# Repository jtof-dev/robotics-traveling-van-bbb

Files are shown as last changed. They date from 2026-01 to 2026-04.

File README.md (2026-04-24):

# ball and beam robot

everything needed to power a ball and beam balance robot (bbb) using a stepper motor, including the code, parts lists, CAD model, and instructions. when you're done, check out our [inverted pendulum robot](https://github.com/jtof-dev/robotics-traveling-van-ipr) and our [website](https://sce.nau.edu/capstone/projects/EE/2026/RoboVan/)

```ascii flowchart
                              ┌─────────┐
                              │         │
                              │ initial │
                              │  boot   │
                              │         │
                              └────┬────┘
                                   │
            ┌───────────────┐      │      ┌─────────────┐
            │               │      │      │             │
            │ reset beam to │◄─────┼─────►│ set up pins │
            │    center     │      │      │ and sensor  │
            │               │      │      │             │
            └───────────────┘      │      └─────────────┘
                                   ▼
                              ┌────────┐
                              │        │
                              │ main() │
                              │        │
                              └────┬───┘
                                   │
                                   │
                                   │
                                   ▼
  ┌────────────────┐      ┌──────────────────┐      ┌───────────────┐
  │                │      │                  │      │               │
  │  send desired  ├─────►│ write a frame to ├─────►│ read time of  │
  │ angle to motor │      │ the touchscreen  │      │ flight sensor │
  │                │      │                  │      │               │
  └────────────────┘      └──────────────────┘      └────────────┬──┘
     ▲                                                           │
     │                                                           │
     │                                                           │
     │                                                           │
     │                                                           │
     │    ┌─────────────────────┐      ┌─────────────────────┐   │
     │    │                     │      │                     │   │
     └────┤ adjust output value │◄─────┤ run PID calculation │◄──┘
          │                     │      │                     │
          └─────────────────────┘      └─────────────────────┘
```

# notes

## directory structure

- **datasheets/**: datasheets for the specific parts used in this robot
- **lib/**: contains all submodules
- **scripts/**: all scripts commonly used while writing code
- **sims/**: any python scripts used to model the behavior of the inverted pendulum
- **src/**: our own written code, split into a `configuration.hpp` and `main.cpp`, along with some extra functions split off into individual files

# software

because there are no good screen libraries written for the pi pico, we are instead using one written for arduino, and then compiling a mixture of arduino and pico code

## building

- first, fetch all submodules with `git submodule update --init --recursive` or delete and re-clone all submodules with `scripts/submoduleSetup.sh`

- second, install two `arduino-cli` (and `arduino-cli` if needed) dependencies that get used in `CMakeLists.txt`:

```bash
arduino-cli core update-index --additional-urls https://github.com/earlephilhower/arduino-pico/releases/download/global/package_rp2040_index.json
arduino-cli core install rp2040:rp2040 --additional-urls https://github.com/earlephilhower/arduino-pico/releases/download/global/package_rp2040_index.json
```

then build with CMAKE (or with `scripts/buildFresh.sh`):

```bash
    mdkir build
    cd build
    cmake ..
    make
```

(note: updating configurations in `src/configuration.hpp` does not trigger a proper re-build, so only running `make` will often not be enough. instead re-run all of the commands or use `scripts/buildFresh.sh`)

## uploading

- to flash the compiled `.uf2`, either reboot the pico into BOOTSEL mode (hold the BOOTSEL button and plug in the pico), or use `picotool` (or `scripts/upload.sh`):

```bash
picotool load -f -x flash.uf2
```

## submodules

- [bodmer/TFT_eSPI](https://github.com/Bodmer/TFT_espi)
- [raspberrypi/pico-sdk](https://github.com/raspberrypi/pico-sdk)
- [yspreen/VL53L0X-driver-pico-sdk-cpp](https://github.com/yspreen/VL53L0X-driver-pico-sdk-cpp)

## sims

- located in `sims/`, and models the expected behavior of the robot. theoretically, it should produce similar gain values to what will be used on the physical robot
- the python environment is managed with `uv`:

```bash
uv sync
uv run main.py
```

or, install `matplotlib` and run normally

# hardware

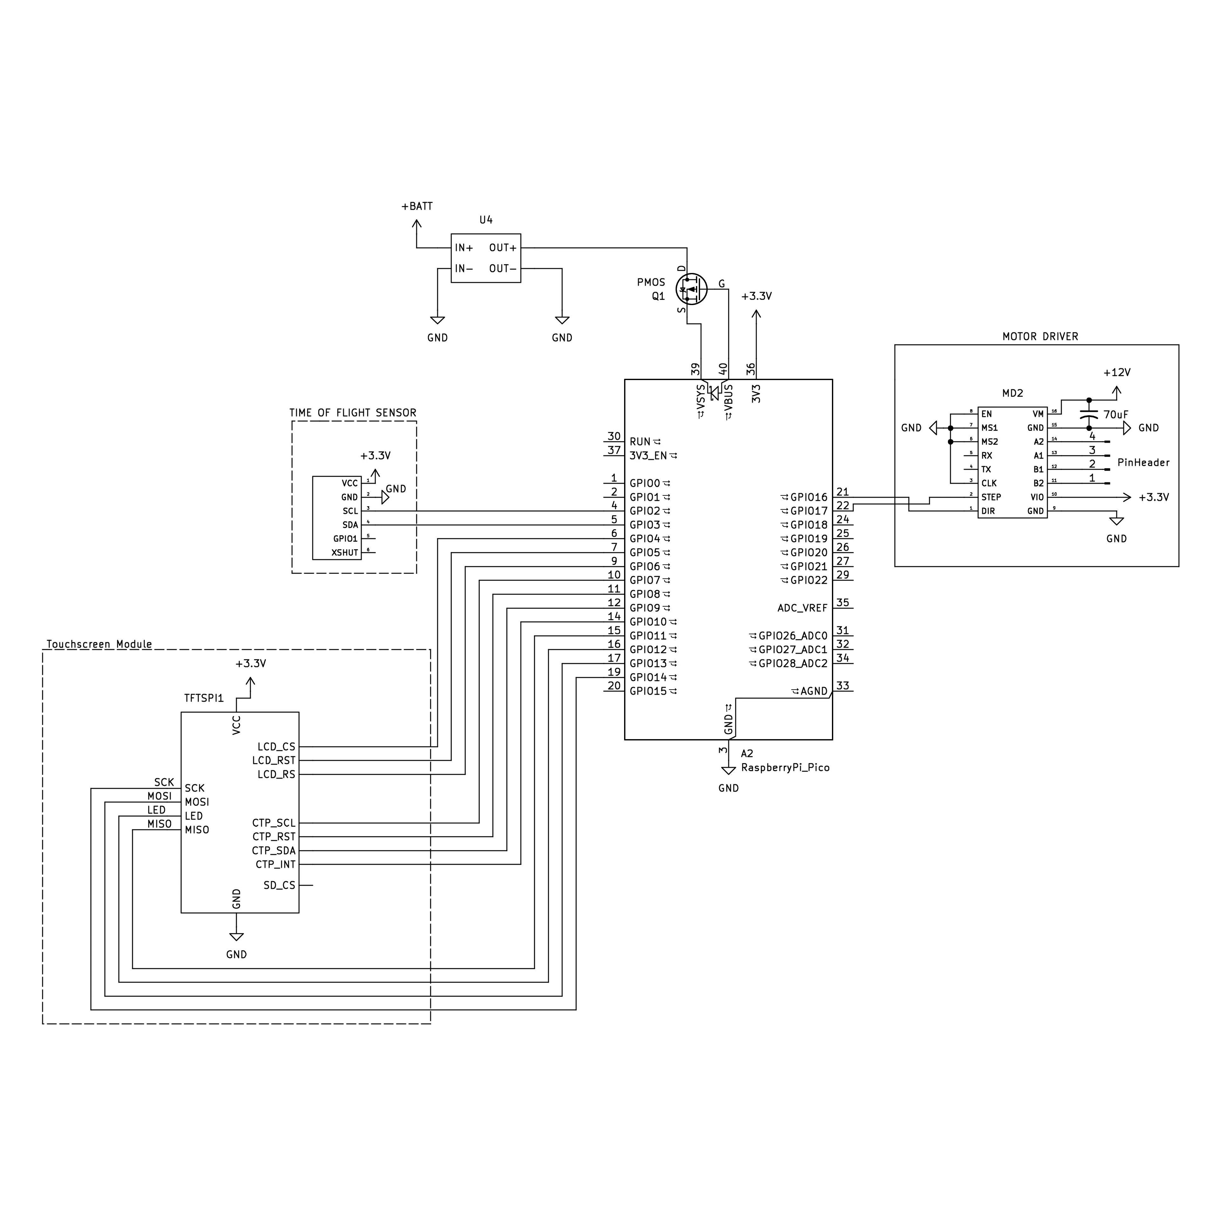
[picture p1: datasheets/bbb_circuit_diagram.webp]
circuit diagram


- for CAD model assembly and instructions, check out [`CAD/`](https://github.com/jtof-dev/robotics-traveling-van-bbb/tree/main/CAD)

## parts list

- [NEMA 17](https://a.co/d/05dRpuKu) stepper motor
- raspberry pi pico or [RP2040](./datasheets/RP2040_datasheet.pdf) compatible board
- [TMC2209](./datasheets/TMC2209_datasheet.pdf) stepper motor driver
- touchscreen with [ST7796S](./datasheets/ST7796S_datasheet.pdf) display driver
- [VL53L0X](./datasheets/VL53L0X_datasheet.pdf) time of flight sensor

### generic parts

- 4-pack of 3.3V batteries (in series for 13V total), matching BMS, and charger
  - be sure to match max voltage, current, and battery chemistry type between all three components
- step-down voltage converter to 3.3V
- 470uF 25V electrolytic capacitor

## pin configuration

### RP2040

| **pin** | **connection** |
| :--- | :--- |
| VIN | schottky diode cathode |
| GND | buck converter GND |
| 3V3 | to rail on protoboard  |
| pin 6 | I2C1 SDA on VL53l0X |
| pin 7 | I2C1 SCL on VL53l0X |
| pin 16  | STEP on TMC2209 |
| pin 17  | DIR on TMC2209 |

### ST7796S touchscreen

| display pin | pi pico pin | notes / function | wire color |
| :--- | :--- | :--- | :--- |
| VCC | external 3.3V | power for the display | red |
| GND | common GND | ground | black |
| LCD_CS | GP21 | TFT chip select (`TFT_CS`) | orange |
| LCD_RST | GP20 | TFT reset (`TFT_RST`) | yellow |
| LCD_RS | GP22 | TFT data/command (`TFT_DC`) | green |
| SDI (MOSI) | GP19 | SPI data input (`TFT_MOSI`) | blue |
| SCK | GP18 | SPI clock (`TFT_SCLK`) | purple |
| LED | 3.3V | backlight power. connect to 3.3V external power, it will overdraw the pico if connected to a data pin | white |
| SDO (MISO) | GP0 | SPI data output (`TFT_MISO`) | gray |
| CTP_SCL | GP3 | I2C1 clock (capacitive touch) | orange |
| CTP_RST | GP6 | touch reset | yellow |
| CTP_SDA | GP2 | I2C1 data (capacitive touch) | green |
| CTP_INT | GP7 | touch interrupt | blue |
| SD_CS | -- | SD card chip select (shares SPI bus with TFT) | -- |

### TMC2209 stepper motor driver

| **pin** | **connection source** | **function**  | **notes** |
| --- | --- | --- | --- |
| VM | 12V power | motor voltage | -- |
| GND | 12V GND | power ground  | -- |
| VIO | 3.3V (pico) | logic voltage | -- |
| GND | GND (pico) | logic ground  | -- |
| STEP | pin 16 (pico) | step signal | -- |
| DIR | pin 17 (pico) | direction | -- |
| EN | GND (pico) | enable | active low (always ON) |
| MS1 | -- | microstep 1 | active low (for 1/8 microstepping) |
| MS2 | -- | microstep 2 | active low (for 1/8 microstepping) |
| A1 | A+ | phase A | red |
| A2 | A- | phase A | black |
| B1 | B+ | phase B | yellow |
| B2 | B- | phase B | blue |

### VL53l0X time of flight sensor

| **pin** | **pico pin / rail** | **function** | **notes** |
| --- | --- | --- | --- |
| VCC | 3.3V rail | power | -- |
| GND | GND rail | ground | -- |
| SDA | GP6 (pin 9) | I2C1 SDA | primary data |
| SCL | GP7 (pin 10) | I2C1 SCL | primary clock |
| XSHUT | -- | shutdown | leave disconnected or pull high |
| GP101 | -- | interrupt | not required for basic ranging  |

# todo

- [ ] make a robust reset that doesn't involve turning on and off
- [ ] make the set point controllable through screen
- [x] detect ball nonsense (i.e its stuck on one side)
- [x] detect absense of ball 
- [x] implement the screen

# contributors

### [Kyle Draper](https://github.com/Kdra-bit)

- developed the electronics and balancing software for the ball and beam balance robot

### [Andy Babcock](https://github.com/jtof-dev)

- assisted with the balancing software and assembly

### [Kaden Zaremba](https://github.com/kadenisuhhh)

- developed the touchscreen software

### [David Jimenez]()

- assisted with the electronics design and assembly

### [Freddy Rivera](https://www.linkedin.com/in/freddy-rivera-791513268/)

- developed the CAD model and helped with assembly

### [Florence Fasugbe](https://www.linkedin.com/in/florence-fasugbe/)

- developed the CAD model and helped with assembly

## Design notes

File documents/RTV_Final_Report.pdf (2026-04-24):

# Robotics Traveling Van

# Final Design Report

### Freddy Rivera – Project Manager

### Colin Parsinia – Manufacturing Lead

### Florence Fasugbe – Design Lead

### Andres Gonzales – Programming Lead

### Fall 2025-Spring 2026

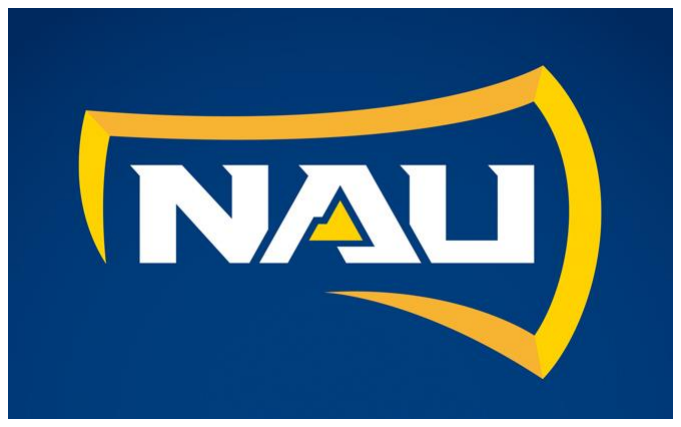
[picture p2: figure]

Project Sponsor: Dr. Michael Shafer

Faculty Advisor: Professor David Willy

Sponsor Mentor: Sethuprasad Gorantla

Instructor: Professor David Willy

i

## DISCLAIMER

This report was prepared by students as part of a university course requirement. While considerable effort has been put into the project, it is not the work of licensed engineers and has not undergone the extensive verification that is common in the profession. The information, data, conclusions, and content of this report should not be relied on or utilized without thorough, independent testing and verification. University faculty members may have been associated with this project as advisors, sponsors, or course instructors, but as such they are not responsible for the accuracy of results or conclusions.

ii

## EXECUTIVE SUMMARY

The Robotics Traveling Van project aims to design and develop two low-cost, transportable educational robots that demonstrate core control-system engineering concepts for K–12 outreach. Sponsored by our client, the goal is to create systems that are safe, durable, engaging, and capable of visually illustrating feedback control in classroom environments. The project spans two semesters, with the first focused on research, concept development, prototyping, and feasibility analysis.

Two robots were selected for development: Robot #1, an Inverted Pendulum Robot, and Robot #2, a Ball-on-Plate Robot. These concepts were chosen based on customer requirements, benchmarking, manufacturability, educational value, and system complexity. Throughout the Fall semester, the team completed detailed requirements definition, House of Quality, literature review, morphological chart, and decision matrices that guided the selection of the final designs.

For Robot #1, the team investigated pendulum dynamics, mass distribution, and actuator requirements to validate that the system could be controlled within safe operating limits. Structural concepts were evaluated for durability and stability, and a final frame design was selected based on manufacturability and robustness. Early prototyping confirmed feasibility and informed next semester’s full build and controller development.

For Robot #2, multiple concepts were researched before selecting the Ball-on-Plate mechanism due to its strong educational impact and clear visualization of closed-loop control. A Failure Modes and Effects Analysis identified critical risks such as motor overheating, unstable motion, and sensing error. A Ball-on-Beam prototype was constructed to validate sensing, actuation, and motor torque requirements prior to scaling to the full plate system. Engineering calculations confirmed that the chosen stepper motors provide sufficient torque with a comfortable safety factor. A detailed Bill of Materials was developed for the final Ball-on-Beam system, along with planned testing procedures for response time, stability, and safety.

Budget tracking, scheduling, and resource planning were completed for both robots, keeping the project within financial constraints. The team then began the process of ordering materials and electrical components so fabrication and system assembly could begin. 3D printers were acquired and a majority of the major components of the system were fabricated using said systems, with minor machining for the few non plastic parts. With both systems physical components assembled testing began for each robot focusing on safety and dimensions, battery endurance, interface and control systems, PID stability, and sensor calibration for both robots. Additionally, robot 1 was subjected to a drop test to ensure its structural integrity in the event of it rolling off a table, and a final bill of materials audit was performed to evaluate the exact cost of an individual unit.

At the current time Robot #2 is fully functional and ready to be handed off to the client for use, while Robot #1 is only capable of movement and not fully capable of balancing its pendulum, though the client has been briefed on the state of Robot #1 and has approved the descoping of required functionality. Looking forward for both robots, the first major step is to get the designed circuit boards printed and implemented into the robots control systems, further wire and electrical system organization, and with a fully functional electrical system implemented into Robot #1 its code can be properly tested & tuned to balance the pendulum.

iii

## TABLE OF CONTENTS

## Contents

DISCLAIMER | 1
EXECUTIVE SUMMARY | 2
TABLE OF CONTENTS | 3
1 | BACKGROUND | 1
1.1 | Project Description | 1
1.2 | Deliverables | 1
1.3 | Success Metrics | 1
2 | REQUIREMENTS | 3
2.1 | Customer Requirements (CRs) | 3
2.2 | Engineering Requirements (ERs) | 3
2.3 | House of Quality (HoQ) | 5
3 | Research and Benchmarking for the Inverted Pendulum Robot | 5
3.1 | Benchmarking for Inverted Pendulum (Robot 1) | 5
3.2 | System-Level Benchmarking | 6
3.2.1 | Balancing Sensor | 6
3.2.2 | Microcontroller | 7
3.2.3 | Motors | 7
3.3 | Literature Review (Robot 1) | 8
3.3.1 | Andres | 8
3.3.2 | Colin | 10
3.4 | Mathematical Modeling (Robot 1) | 12
3.4.1 | Control System and Pendulum Dynamics – Andres Gonzales | 12
3.4.2 | Pendulum Robot Frame Structural Integrity – Colin Parsinia | 12
3.4.3 | Cart/Angular Acceleration for an Inverted Pendulum – Freddy Rivera | 13
3.4.4 Inverted Pendulum Robot , Reference within Humans – Florence L. Fasugbe | 14
4 | Research and Benchmarking for the Ball-On-Beam Robot | 15
4.1 | Benchmarking for Ball-On-Beam (Robot 2) | 15
4.2 | System-Level Benchmarking | 15
4.2.1 | Distance Sensor Benchmarking | 16
4.2.2 | Microcontroller Benchmarking | 16
4.2.3 | Actuator Benchmarking | 16
4.3 | Literature Review (Robot 2) | 17
4.3.1 | Freddy | 17
4.3.2 | Florence | 20
4.4 | Mathematical Modeling (Robot 2) | 21
4.4.1 | Dynamic Physical Limits – Freddy Rivera | 21
4.4.2 | Control System Architecture – Freddy Rivera | 22
4.4.3 | Dynamics of the Beams Structure with - Florence L. Fasugbe | 22
5 | Design Concepts for the Inverted Pendulum Robot | 24
5.1 | Functional Decomposition | 24
5.2 | Concept Generation | 24
5.3 | Selection Criteria | 26
5.4 | Concept Selection | 27
6 | Design Concepts for the Ball on Beam System | 28
6.1 | Functional Decomposition | 28
6.2 | Concept Generation | 29
6.3 | Selection Criteria | 31

iv

6.4 | Concept Selection | 32
7 | Schedule and Budget | 35
7.1 | Schedule | 35
7.2 | Budget | 35
7.3 | Bill of Materials (BoM) | 36
8 | Design Standards | 39
8.1 | Design Standards Research | 39
Robot 1: | 39
8.1.1 | Robot 1 Annotated Bibliography: | 40
8.1.2 | Robot 2: | 40
8.1.3 | Annotated Bibliography: | 42
8.2 | Design Standards Used | 43
8.2.1 | Robot 1 & 2: | 43
9 | Design Validation and Initial Prototyping for Both Systems | 45
9.1 | Failure Modes and Effects Analysis (FMEA) for Inverted Pendulum | 45
9.2 | Failure Modes and Effects Analysis (FMEA) for Ball-on-Beam | 46
9.3 | Initial Prototyping | 48
9.3.1 | Robot 1 Prototype | 48
9.3.2 | Robot 2 Prototype | 50
9.4 | Other Engineering Calculations | 51
9.4.1 | Other Engineering Calculations – Colin Parsinia & Andres Gonzales | 51
9.4.1.1 | Electrical Load Analysis | 51
9.4.2 | Other Engineering Calculations for Robot 2– Freddy Rivera & Florence Fasugbe52
9.4.2.1 | System Parameters | 53
9.4.2.2 | Plant Model Summary | 53
9.4.2.3 | Available Motor Torque at Operating Conditions | 54
9.4.2.4 | Load Case 1: Static Torque Requirement | 54
9.4.2.5 | Load Case 2: Maximum Allowable Angular Acceleration | 54
9.4.2.6 | Total Rotational Inertia | 54
9.4.2.7 | Required Dynamic Torque | 54
9.4.2.8 | Load Case 3: Maximum Recoverable Beam Angle (Rolling Without Slip)54
9.4.2.9 | Battery Runtime Estimate | 55
9.4.2.10 | Structural Factor of Safety Summary | 55
9.4.2.11 | Design Implications | 55
9.5 | Future Testing Potential | 55
10 | Final Hardware | 56
10.1 | Final Physical Design – Robot #1 | 56
10.2 | Final Physical Design – Robot #2 | 61
11 | Final Testing | 65
11.1 | Top level testing summary table | 65
11.2 | Detailed Testing Plan | 66
11.2.1 | Test 1: Safety & Dimensions | 66
11.2.1.1 | Summary | 66
11.2.1.2 | Procedure | 66
11.2.1.3 | Results | 66
11.2.2 | Test 2: Bill of Materials Audit | 67
11.2.2.1 | Summary | 67
11.2.2.2 | Procedure | 67
11.2.2.3 | Results | 67
11.2.3 | Test 3: Chassis Drop Test | 67
11.2.3.1 | Summary | 67

v

11.2.3.2 | Procedure | 67
11.2.3.3 | Results | 67
11.2.4 | Test 4: Battery Endurance | 67
11.2.4.1 | Summary | 67
11.2.4.2 | Procedure | 68
11.2.4.3 | Results | 68
11.2.5 | Test 5: Interface & Control | 68
11.2.5.1 | Summary | 68
11.2.5.2 | Procedure | 68
11.2.5.3 | Results | 68
11.2.6 | Test 6: PID Stability & Settling | 69
11.2.6.1 | Summary | 69
11.2.6.2 | Procedure | 69
11.2.6.3 | Results | 69
11.2.7 | Test 7: Sensor Calibration | 69
11.2.7.1 | Summary | 69
11.2.7.2 | Procedure | 69
11.2.7.3 | Results | 70
12 | Future work | 71
13 | Conclusion | 72
14 | REFERENCES | 73
15 | APPENDICES | 77
15.1 | Appendix A: Bill of materials (BOM) of Robot #1 and #2 for the RTV Capstone throughout
the 2026 spring semester; listing the products used to manufacture the final product with the name of
parts, vendor, costs, quantity, link of purchases, and dimensions of the products | 77

1 | P a g e

## 1 BACKGROUND

This chapter provides an overview of the project background and objectives. It summarizes the project description, deliverables, and success metrics, outlining how the dual-robot design aligns with client expectations for highly durable, interactive engineering outreach tools designed to entice K-12 students to Northern Arizona University (NAU).

### 1.1 Project Description

The goal of this capstone project is to design and manufacture two highly interactive educational robots that serve as traveling outreach props for NAU. Sponsored by Dr. Michael Shafer, the project aims to create low-cost, durable learning platforms that visually demonstrate fundamental control system principles to inspire K-12 students to pursue STEM.

Each robot fulfills a unique educational role:

- Robot #1 (Inverted Pendulum): Demonstrates Newtonian dynamics, physical mobility, and spatial tracking through magnetic encoders (with active PID balancing formally descoped to prioritize structural resilience and reliable component integration).
- Robot #2 (Ball-on-Beam): A 1-axis, direct-drive system designed to visually demonstrate active Proportional-Integral-Derivative (PID) feedback control through hands-on interaction.

While the project was allocated a total budget of $5,000, the client's core directive was mass-producibility for fleet deployment. To meet this, the team successfully engineered both platforms utilizing off-the-shelf electronics and standard 3D-printed PLA, achieving a highly scalable reproduction cost of under $300 (approximately $240) per unit. Throughout the academic year, the project evolved from theoretical mathematical modeling to the final delivery of robust, physical hardware capable of surviving high-impact K-12 environments.

### 1.2 Deliverables

The major deliverables for this project include:

1. Two fully manufactured educational robots (the Inverted Pendulum and the Ball-on-Beam) equipped with integrated touchscreen interfaces to serve as transportable K-12 outreach tools.
2. An open-source digital repository hosting all necessary CAD models, microcontroller code bases, and mass-manufacturing blueprints, and bill of materials (BOMs) to ensure the client or future engineering teams can seamlessly replicate the fleet.
3. Comprehensive engineering documentation detailing the complete design cycle, functional decompositions, risk mitigation (FMEA) strategies, and finalized system parameters.

### 1.3 Success Metrics

Project success is evaluated against the rigorous customer and engineering requirements established during the early design phases. Key success criteria include:

- Platforms must effectively translate invisible math into observable physical motion: observable physical motion, whether through dynamic spatial tracking or active feedback control loops, to captivate K-

2 | P a g e

12 audiences.

- Interactive Interface: Students must be able to safely alter system variables via the onboard touchscreens without requiring external computer hardware.
- Classroom Durability: The physical chassis must withstand the wear and tear of a K-12 environment. By utilizing thickened 3D-printed PLA architectures and robust mechanical fasteners, both systems are engineered for high structural resilience during continuous transport and hands-on demonstrations.
- Untethered Reliability: Systems must operate completely independently of wall power. Custom 14.8V LiFePO4 battery arrays were integrated to successfully sustain continuous demonstrations for over 90 minutes.
- Mass Producibility & Budget: The final per-unit cost must remain strictly under the $300 target to allow NAU to economically reproduce the designs for future traveling van deployments.

Success has ultimately been verified through final physical testing, performance analysis, and client evaluation, confirming that the constructed platforms meet the rigid safety, durability, and cost metrics required to serve as permanent NAU engineering outreach tools.

3 | P a g e

## 2 REQUIREMENTS

The requirements section establishes the foundational parameters of the project, translating qualitative client needs into measurable, quantifiable engineering goals. Because this project is designed as an interactive engineering outreach spectacle rather than a static classroom tool, the requirements heavily emphasize durability, visual engagement, and mass producibility. Customer Requirements (CRs) describe what the client expects the final platforms to accomplish in plain, qualitative terms. Engineering Requirements (ERs) then translate those needs into verifiable parameters with measurable targets, units, and one-sided, two-sided, or binary constraints. Finally, the House of Quality (HoQ) matrix visually maps the relationships between CRs and ERs, highlighting critical design trade-offs and driving prioritization decisions.

### 2.1 Customer Requirements (CRs)

The primary client goal is to create a transportable, interactive spectacle that demonstrates feedback control principles to K-12 students, with the intent of enticing them to pursue STEM at NAU. The CRs below stem from the intended user base, the need for mass producibility, and the survivability demands of high-impact outreach environments.

Table 1: Customer Requirements

CR # | Title | Description
CR01 | Durable | The robot must withstand frequent use, rough handling, and physical impacts common in K-12 outreach environments.
CR02 | Inexpensive | The total production cost must be low enough to enable fleet-wide mass production for NAU outreach programs.
CR03 | Functional | The system must effectively demonstrate the principles of feedback control through observable, repeatable mechanical motion.
CR04 | Battery Powered | The system must operate completely untethered from external power sources to ensure maximum flexibility and safety during demonstrations.
CR05 | Interactive Interface | The interface must allow users to directly adjust control parameters and initiate demonstrations intuitively.
CR06 | Compact Operating Space | The robot must safely function on a standard classroom or lab table without requiring excessive operational clearance.
CR07 | Educational / Engaging | The design must help students visually and conceptually connect physical robot motion with control theory concepts.
CR08 | Kid-Friendly Design | The product must be visually appealing, approachable, and physically safe for students of all ages.

### 2.2 Engineering Requirements (ERs)

The ERs below translate each qualitative CR into a strict, verifiable target. All constraints are expressed with explicit units and limit types. Note regarding ER07: Following mid-project client review, active PID balancing for the Inverted Pendulum (Robot 1) was formally descoped in favor of focusing on dynamic mobility. ER07 therefore applies exclusively to the Ball-on-Beam (Robot 2) automated balancing system.

4 | P a g e

Table 2: Engineering Requirements

ER # | Title | Target | Unit | Constraint Type | Linked CR(s) | Rationale
ER01 | Overall Dimensions | < 12 × 12 × 12 | inches | One-sided (max) | CR06, CR08 | Ensures high transportability and compatibility with standard storage and tabletop outreach setups.
ER02 | Runtime / Power Source | > 30 | minutes | One-sided (min) | CR03, CR04 | Must sustain continuous operation through a full outreach event on a single charge.
ER03 | Control Hardware | Raspberry Pi (RP2040/Pico) | Binary (Yes/No) | Binary | CR03, CR05 | Microcontroller must support real-time sensor filtering and drive interactive touchscreen displays.
ER04 | Electrical Safety | Fully Enclosed Wiring | Binary (Yes/No) | Binary | CR08 | Complies with U.S. CPSC guidelines; eliminates exposed conductors and short-circuit risk around children.
ER05 | Drop Test Survivability | 36 | inches | One-sided (min) | CR01 | Must survive a fall from a standard laboratory table without mechanical failure.
ER06 | Manufacturing Cost | < 300 | USD/unit | One-sided (max) | CR02 | Keeps per-unit reproduction cost low enough for NAU to scale the project into a larger fleet.
ER07 | PID Settling Time | < 15.0 | seconds | One-sided (max) | CR03, CR07 | Allows users enough time to observe system oscillation before equilibrium is reached. (Robot 1 active balancing descoped; applies to Robot 2 only.)
ER08 | Sharp Edge Radii | ≥ 3 | mm | One-sided (min) | CR08 | All exposed edges must be chamfered or filleted to eliminate laceration hazards per CPSC guidelines.
ER09 | Pinch-Point Clearance | ≥ 16.5 | mm | One-sided (min) | CR08 | Maintains safe spacing between all moving parts to prevent finger entrapment per toy safety standards.
ER10 | Emergency Stop Response | < 1.0 | seconds | One-sided (max) | CR08 | A physical cutoff must instantly sever power to all actuators in the event of

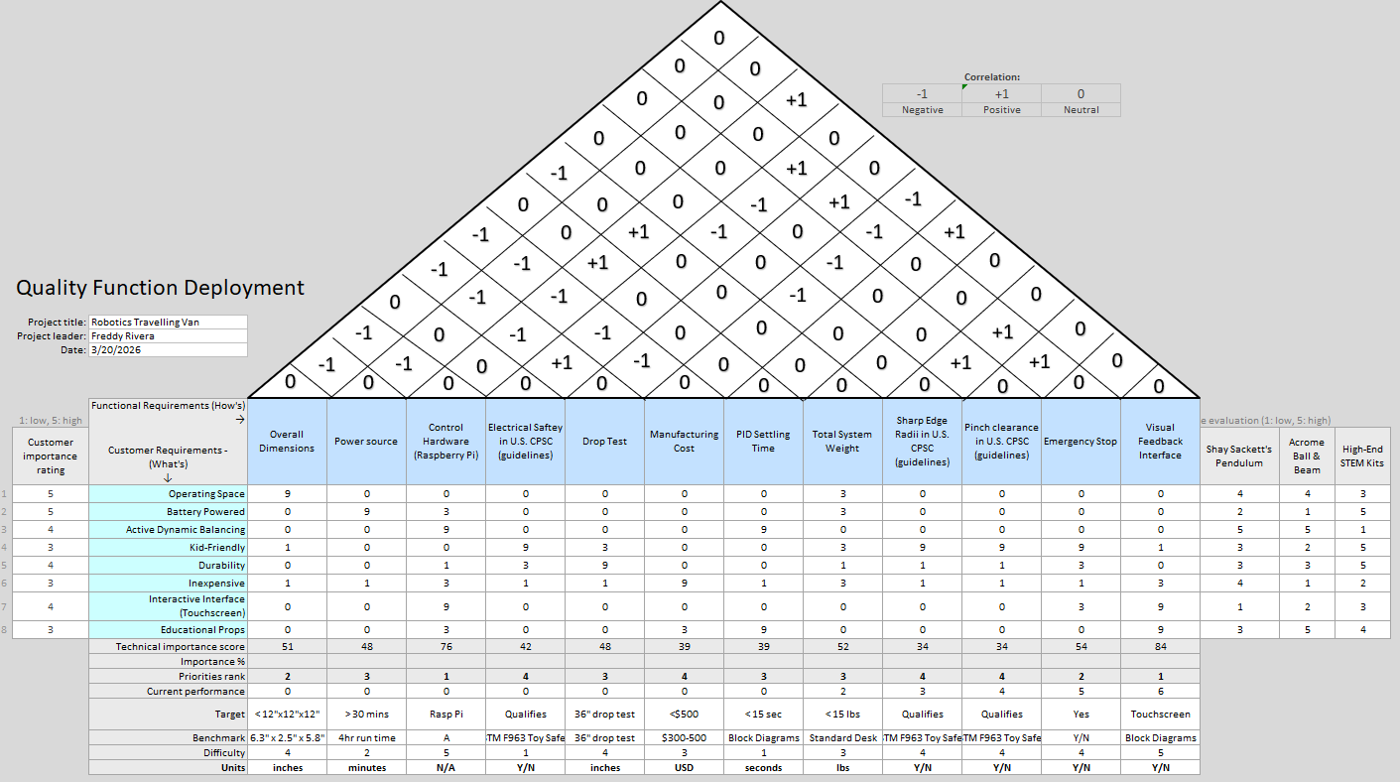
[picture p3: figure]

5 | P a g e
| | | | | | unpredictable behavior.
ER11 | Visual Feedback Interface | LCD Touchscreen | Binary (Yes/No) | Binary | CR05, CR07 | Provides the primary interaction point for students to modify control variables and observe live mechanical data.

### 2.3 House of Quality (HoQ)

Figure 1: House of Quality

## 3 Research and Benchmarking for the Inverted Pendulum Robot

### 3.1 Benchmarking for Inverted Pendulum (Robot 1)

The development of our inverted pendulum robot is guided by benchmarking against established, state-of-the-art systems. Because self-balancing robotics is a well-documented field, there is a wealth of existing control architectures and mechanical designs to inform our original build.

The systems selected for system-level comparison include Shay Sackett’s Pendulum Robot, a Voice-Controlled Self-Balancing Robot, and an Instructables Line-Following Robot. The first two benchmarks serve as direct

6 | P a g e

mechanical and control comparisons for two-wheeled inverted pendulums. The third system serves as a conceptual benchmark for K-12 user interactivity.

### 3.2 System-Level Benchmarking

Table 3: Robot 1 Benchmarking – top level systems
System | Reference
Example | Key Features | Relation to Our
Concept | Notes / Takeaways

Sackett’s
Pendulum
Robot

Shay Sackets
Self Balancing
Pendulum
Robot [34]

2-Wheeled
Pendulum robot
capable out
automatic balancing
mid operation

Provides solid baseline
design for a 2-Wheeled
Pendulum robot

Establishes basic ideas,
equations, principles, and systems that go into
pendulum robots

Self-Balancing
Interactive
Robot

Voice controlled
self-balancing
pendulum robot
[19]

2-Wheeled
Pendulum robot
capable of receiving
voice commands and
interacting with
external systems

Proof of concept of a
voice-controlled
pendulum robot for
good interactivity

Presents alternative,
higher-level control
mechanisms. While highly
complex, it validates the
feasibility of advanced
interactivity.

Instructible
Line
Following
Robot

Instructable
Line following
robot [33]

Simple 3 wheeled
line following robot,
easy system to
assemble and
explain

The tactile interactivity
(users physically
drawing the path the
robot follows) is ideal
for K-12 engagement.

When designing our robot,
achieving a similar level
of intuitive, hands-on
interactivity is a primary design target.

### 3.2.1 Balancing Sensor

To ensure optimal performance, durability, and cost-effectiveness, the primary sub-systems of our inverted pendulum robot, specifically the balancing sensor, microcontroller, and actuators were benchmarked against industry-standard alternatives.

Table 4: Robot 1 Benchmarking – sensors

Feature /
Metric

Alternative 1: IMU (e.g.,
MPU6050) [25]

Alternative 2: Optical
Encoder [50]

Selected: Magnetic
Encoder

Measurement
Method | Gravity/Acceleration Vectors | Light interruption via slotted disk

Magnetic field variation
(Hall Effect)

7 | P a g e

Susceptibility to
Drift

High (Requires
Kalman/Complementary filters) | None | None

Environmental
Durability | High | Low (Sensitive to dust/debris)

High (Contactless and
sealed)

Integration
Complexity | High (Complex math overhead) | Medium | Low (Direct digital/analog output)

While Inertial Measurement Units (IMUs) are the standard, our cart-and-pendulum mechanical design allows for a fixed axis of rotation. Benchmarking reveals that placing a magnetic encoder directly on this axis provides immediate, absolute angular position data. This eliminates the computational overhead and signal drift associated with filtering IMU data, while offering greater physical durability than an optical encoder.

### 3.2.2 Microcontroller

The microcontroller must be capable of rapidly polling the encoder, computing the PID algorithm, and outputting precise PWM signals to the motor drivers without stalling.

Table 5: Robot 1 Benchmarking - microcontroller

Feature / Metric Alternative 1: Arduino Uno (ATmega328P) [41]

Alternative 2:
ESP32 [35]

Selected: Raspberry Pi Pico (RP2040)
Clock Speed | 16 MHz | 240 MHz | 133 MHz
Architecture | 8-bit, Single-Core | 32-bit, Dual-Core | 32-bit, Dual-Core (ARM Cortex-M0+)

Programmable
I/O (PIO) | No | No | Yes (Dedicated PIO state machines)
Cost | ~$20.00 | ~$10.00 | ~$4.00

The Arduino Uno is heavily documented but severely limited by its 16 MHz clock speed, which can introduce latency into high-frequency control loops. While the ESP32 offers superior processing power and wireless capabilities, it introduces unnecessary power consumption and complexity for this specific scope. The Raspberry Pi Pico is the optimal benchmarked choice; its dual-core architecture allows one core to continuously poll the high-resolution magnetic encoder while the second core calculates the PID response and drives the motors, all at a highly cost-effective price point.

### 3.2.3 Motors

The actuation system must move the base cart rapidly in two directions to keep the pendulum balanced. Our mechanical design utilizes a 4-wheel cart base requiring integrated motors.

8 | P a g e

Table 6. Robot 1 Benchmarking - actuators

Feature /
Metric

Alternative 1: NEMA 17
Stepper Motors [8]

Alternative 2:
Brushless DC (BLDC)
[17]

Selected: 520 DC Reduction Motors (L-Type)

Control
Method

Step pulses (Open-loop
precise)

Electronic Speed
Controller (ESC)

PWM via H-Bridge (L298N /
TB6612FNG)

Torque at
Low Speeds | Very High | Low to Medium | High (Due to integrated
| | | gearbox)

Form Factor /
Mounting | Bulky, heavy | Compact | L-Type configuration (Ideal for
| | | chassis)
Cost & Complexity | High (Requires heavy
| drivers) | Very High | Low (Simple integration)

Stepper motors offer excellent positional accuracy but suffer from a low top-speed and significant weight, BLDC motors provide rapid response times but require expensive ESCs and complex commutation logic. The 520 L-Type DC gear motors were selected because their integrated reduction gearboxes provide the necessary torque to move the 4-wheel cart abruptly. Furthermore, the L-shape form factor is geometrically advantageous for maximizing internal chassis space, and they are easily driven by standard, low-cost H-bridge motor controllers.

### 3.3 Literature Review (Robot 1)

### 3.3.1 Andres

[1] S. O. Fadlallah and K. M. Goher, “Bacterial foraging-optimized PID control of a two-wheeled machine with a two-directional handling mechanism,” Robotics and Biomimetics, vol. 4, no. 1, p. 5, 2017.

This paper presents an innovative PID control method optimized through bacterial foraging algorithms for a two-wheeled robot. Its approach to handling two-directional motion is relevant for our pendulum robot’s control system, offering insights on advanced PID tuning. We will reference this to support our control strategy development, particularly for improving robot stability and response.

[2] X. Yu, Y. Fan, S. Xu, and L. Ou, “A self-adaptive SAC-PID control approach based on reinforcement learning for mobile robots,” International Journal of Robust and Nonlinear Control, vol. 31, no. 21, pp. 8389–8408, 2021.

This article discusses a reinforcement learning-based adaptive PID control for mobile robots, enhancing adaptability in dynamic environments. It applies to our project by informing adaptive control techniques to improve robot performance under varying load and terrain. We will cite this when describing our adaptive control algorithms.

9 | P a g e
[3] S. Jin and Y. Ou, “A wheeled inverted pendulum learning stable and accurate control from demonstrations,” Applied Sciences, vol. 9, no. 24, p. 5279, 2019.

The study explores learning-based control methods for wheeled inverted pendulums, focusing on stability and accuracy through demonstration learning. This is directly relevant for our pendulum robot’s balancing and control challenges. We will reference it to justify the use of machine learning or demonstration data in refining control models.

[4] S. Roy, S. B. Roy, and I. N. Kar, “Adaptive-robust control of Euler-Lagrange systems with linearly parametrizable uncertainty bound,” IEEE Transactions on Control Systems Technology, vol. 26, no. 5, pp. 1842– 1850, 2018. (Note: The title was slightly adjusted upon final publication from the preprint). This paper provides theoretical foundations and practical applications for adaptive-robust control in Euler-Lagrange systems, addressing uncertainties common in mechanical systems like our robot. We will reference this to underpin the robustness of our control system design in the face of modeling inaccuracies.
[5] K. Ogata, System Dynamics, 4th ed. Upper Saddle River, NJ: Prentice Hall, 2003, ch. 11.

Ogata’s textbook is a fundamental resource on system dynamics, providing key concepts in modeling and controlling dynamic mechanical systems, including pendulums. We will cite this as a primary reference for the theoretical background of pendulum dynamics and control principles applied in our design.

[6] PythonRobotics, “Inverted Pendulum Control,” GitHub repository. [Online]. Available: https://github.com/AtsushiSakai/PythonRobotics

This open-source repository provides practical algorithms for inverted pendulum control, including simulation and implementation examples. We will use it as a resource for algorithm development and benchmarking, referencing it when describing our control software framework.

[7] zjor, “Inverted Pendulum on a Cart,” Arduino Project Hub. [Online]. Available: https://projecthub.arduino.cc/zjor/inverted-pendulum-on-a-cart-d4fdfc

This community-driven project provides a practical implementation of a PID control system for an inverted pendulum, a classic problem in control theory and robotics. We will use this resource to understand the mathematical modeling and firmware implementation for balancing and dynamic control, which is essential for our robot’s stability.

[8] MRCE, “Circuit Analysis & Design Introduction.” [Online]. Available: https://mrce.in/ebooks/Circuit%20Analysis%20&%20Design%20Introduction.pdf

This textbook serves as a reference for the fundamental principles of circuit analysis and design. It is for planning the robot's power distribution system, selecting appropriate components (resistors, potentiometer, microcontrollers/arduino), and ensuring the electrical reliability and safety of the final design.

[9] Creality, “CREALITY ENDER-3 V2 3D PRINTER User Manual.” [Online]. Available: https://m.media-amazon.com/images/I/B1f9eP6H3OS.pdf (https://m.media-amazon.com/images/I/B1f9eP6H3OS.pdf)

This user manual details the operation, maintenance, and technical specifications of the Creality Ender-3 V2 3D printer. We will reference this for all additive manufacturing phases, including determining print tolerances, material compatibility, and optimal settings to produce durable, custom-designed robot components and enclosures.

10 | P a g e
[10] Z. C. M. Davidson, S. Dang, and X. Vasilakos, “Blended laboratory design using Raspberry Pi Pico for digital circuits and systems,” IEEE Transactions on Learning Technologies, vol. 17, 2024.

This paper discusses the implementation of digital circuits and systems using modern microcontrollers, specifically highlighting the integration of hardware with Python programming. This is highly relevant to the physical hardware and software architecture of our robot.

[11] S. R. Doty, “Python Basics,” Computer Science, pp. 1–20, 2008.

This document provides foundational concepts, syntax, and structural knowledge for Python programming. Because Python is utilized in our project for algorithm development, control simulations, and scripting our hardware logic, this text serves as a baseline software reference. It supports the software architecture, coding, and scripting frameworks used to drive the robot.

[12] Y. Li, K. H. Ang, and G. C. Y. Chong, “PID control system analysis and design,” IEEE Control Systems Magazine, vol. 26, no. 1, pp. 32–41, Feb. 2006.

This comprehensive article details the analysis, design methodologies, and computational modeling of Proportional-Integral-Derivative (PID) controllers. It is a fundamental resource for our project, as a PID control is the primary mechanism utilized for maintaining the upright dynamic stability of our pendulum robot.

### 3.3.2 Colin

[13] “Manufacturing Robotics: Basic issues and challenges,” Haruhiko H. Asada, 1996. [Online]. Available: https://www.sciencedirect.com/science/article/pii/S147466701757682X

Annotation: This article primarily focuses on how to apply robots in the manufacturing process, but also contains many interesting insights to various manufacturing methods, mass-manufacturing design philosophies, as well as how to design adaptive control systems for robots, providing valuable information on the various fields that must be considered in designing robots and parts.

[14] “How to include User eXperience in the design of Human-Robot Interaction,” Prati, Peruzzini, Pellicciari, Raffaeli, 2021. [Online]. Available: https://www.sciencedirect.com/science/article/pii/S0736584520302805

Annotation: This article covers the subject of human-robot interaction, and how best to design systems for safe and effective interactions. It highlights the importance of structured operations with intervals designed for function and interaction respectively. Through understanding the principles presented by this article, designing an interactive system becomes easier.

[15] “Designing Robots with movement in mind” Hoffman, Ju, 2014. [Online], Available: https://dl.acm.org/doi/10.5898/JHRI.3.1.Hoffman

Annotation: In the design of robots, it is important to consider their range of motion, especially when they work in close proximity of humans, which is what this article focuses on. As the article recommends, it is important to have a clear start up sequence when our robot enters an operational cycle, so ensuring that its movements are clearly readable will greatly reduce risk of injury with people who are unfamiliar with the robots operation.

11 | P a g e
[16] “Design and Implementation of and Open-Source Educational Robot for Hands-On Learning Experiences in IOT,” Mamatnabiyev 2023. [Online], Available: https://ieeexplore.ieee.org/document/10146599

Annotation: This excerpt from a conference covers a design for a modular educational robot which is comprised of components which can be freely added or removed to perform different functions. The intent of the robot is to allow students to freely experiment with different component configurations to see their effects on the robot and the code.

[17] “Design and control of a multi-DOF two wheeled inverted pendulum robot” Dai, Li, Peng, Zhu, Jiang, Gao, 2014. [Online], Available: https://ieeexplore-ieee-org.libproxy.nau.edu/document/7052763

Annotation: This Document presents a design for a two wheeled inverted pendulum robot capable of multiple degrees of freedom, including the math behind the robot’s articulation and movement, the major electronic components being utilized by the system, and graphs displaying the robot’s climbing capabilities. The entire document also lays out the general design process for a pendulum robot, and what factors are most important to consider in order to optimize function.

[18] “Mechanical Design and Dynamic Modeling of a Two-Wheeled Inverted Pendulum Mobile Robot” Li, Gao, Huang, Du, Duan, 2007. [Online], Available: https://ieeexplore-ieee-org.libproxy.nau.edu/document/4338830

Annotation: This Document offers an alternative pendulum robot design, only having 1 degree of freedom, and is instead designed for navigating small spaces for maintenance surveys, and as such the robot is far smaller. This document is not without its own unique insight into robot design, as it contains a great example of a control system diagram, a very useful visualization of an otherwise complicated system, as well as providing some examples of the type of mechanisms useful for measuring the angle of the robot and other systems.

[19] “Design and Implementation of Self-Balancing Interactive Robot,” Siddhartha, Gosh, D.M., 2023. [Online], Available: https://ieeexplore-ieee-org.libproxy.nau.edu/document/10584954

Annotation: This Pendulum Robot is unique amongst other designs examined previously as it implements a voice control system for added interactivity. These added systems introduce a fair amount of complexity to the control system diagram but presents great opportunity for interactivity which could be practical in an educational setting. Additionally, the document cites a great number of additional works which can be used to design one’s own pendulum robot.

[20] “3D printing threads and adding threaded inserts to 3D printed parts (with video),” Formlabs, [Online], Available https://formlabs.com/blog/adding-screw-threads-3d-printed-parts/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 (https://formlabs.com/blog/adding-screw-threads-3d-printed-parts/)

Annotation: This short article describes multiple methods to utilize screws on 3-D printed parts. The methods highlighted include utilizing a variety of threaded inserts, pre-tapping the holes, utilizing self tapping screws, or 3-D printing threads. Each method comes with its own upsides and downsides when it comes to the complexity of instillation, durability under multiple assembly and disassembly cycles, and overall thread strength, which will help the decision making process when creating screw mounts.

[21] “Polylactic acid (PLA) Filament Review,” JuggerBot 3D, [Online], Available https://juggerbot3d.com/pla-filament-review/ (https://juggerbot3d.com/pla-filament-review/)

12 | P a g e

Annotation: This article reviewing PLA plastic filament contains a number of useful insights as to the material properties of the material as well as the optimal operating temperatures for the 3D printer nozzle, bed, and nozzle speed to use while working with the material.

[22] “Ultimate Guide: How to design for 3D Printing,” WikiFactory, 2020. [Online], Available https://wikifactory.com/+wikifactory/stories/ultimate-guide-how-to-design-for-3d-printing

Annotation: This article highlights a variety of useful principles to keep in mind when designing parts for 3D printing, including minimum feature sizes, how to set up parts in slicing software for optimal adhesion, how to account for the filament expanding as it hardens and how it affects features like holes, and various other manufacturing errors and how to avoid them. Its insights into the particulars of 3D printing can prove invaluable to those less experienced in this manufacturing method.

### 3.4 Mathematical Modeling (Robot 1)

### 3.4.1 Control System and Pendulum Dynamics – Andres Gonzales

To maintain the upright dynamic stability of the U-shaped pendulum arm, a Proportional-Integral-Derivative (PID) control algorithm is implemented on the Raspberry Pi Pico. The microcontroller processes data in discrete time steps, so the control loop relies on a discrete-time PID equation to calculate the required motor output based on the angular error measured by the magnetic encoder [12].

The discrete-time PID control law applied to our system is:

(1)

Where:

- uk = Motor control signal (PWM duty cycle) at the current time step k
- ek = Angular error at the current time step (Target Angle - Measured Angle)
- ek−1 = Angular error at the previous time step
- Kp, Ki

, Kd = Proportional, Integral, and Derivative tuning gains
- Ts = Sampling period of the Pi Pico control loop (seconds)

The mathematical model of the pendulum's physics was initially simulated using MATLAB and Simulink to determine theoretical baseline values for the Kp, Ki

, and Kd gains prior to physical deployment and extensive tuning on the hardware.

### 3.4.2 Pendulum Robot Frame Structural Integrity – Colin Parsinia

Due to the project requirement to be mass-producible, the main component we are required to design from scratch is the robot’s frame. Referring to the engineering requirements, the main goal of our frame design is to be able to survive a fall off a table onto a concrete surface, and the main means of ensuring the frame is capable of doing so is by utilizing a modified variation of the flexural strength equation and finding the necessary thickness of our material to resist the force imposed by the fall. First, It is important to define the variables that will be plugged into the following equations. In the list below, each known variable, its associated value, and unit is listed.

13 | P a g e

m = 3 [kg], g = 9.81 [

m
s

2

], ℎ = 0.762 [m], L = 0.254 [m], b = 0.127, ∆t = 0.005 [s]

Next, to find the force of impact due to a fall, the below equation (1) is used. which necessitates finding the velocity of the robot falling from the height of an average table
V = √2gℎ (1)

Plugging in our known values results in a velocity of 3.867 [m/s] which can then be used in the force equation (2) to find the force of impact on our robot
F =
mv ∆t | (2)

The calculated force of impact is 2,319 Newtons, which is one of the two remaining unknown variables needed to calculate the thickness required to resist impact, the other being the flexural strength of our material. Our client requested that the robot frame be made primarily of 3-D printable materials, so after some quick research, a list of the flexural strengths of common 3-D printing plastics, the following list was found.
σflex PLA = 97 [Mpa]
σflex TPLA = 83 [Mpa]
σflex ABS = 60 [Mpa]
σflex PC = 89 [Mpa]
σflex PETG = 75 [Mpa]
σflex N = 75 [Mpa]
Now, with all these variables values ascertained, the final equation (3) can be utilized to find the minimum required thickness to resist the impact force from falling for each material, narrowing down the selection process to the best material to use for the robot frame. The minimum thickness equation and the calculated minimum thicknesses can be found in the list below.
ℎ ≥ √
6FL bσflex | (3)

ℎmin,PLA = 16.94 [mm]
ℎmin,TPLA = 18.31 [mm]
ℎmin,ABS = 21.54 [mm]
ℎmin,PC = 17.69 [mm]
ℎmin,PETG = 19.27 [mm]
ℎmin,N = 19.27 [mm]
With these known values, the robots frame can be designed to survive the client’s fall test and should also resist the common forces experienced by the robot during everyday operations.

### 3.4.3 Cart/Angular Acceleration for an Inverted Pendulum – Freddy Rivera

To analyze the dynamics of Robot #1 (Inverted Pendulum), the team modeled the system as a classical cart-and-pendulum configuration, where a horizontally driven cart stabilizes an inverted pendulum through active feedback control.

The mathematical foundation for this analysis was based on the work by A. Md. Khairul Alam et al. [26], which applies Newtonian dynamics to model both translational and rotational motion.

Cart (horizontal motion):

14 | P a g e

(M + m)ẍ+ mℓθ̈cos(θ) − mℓθ̇² sin(θ) = F (6)

Pendulum (rotational motion): ℓθ̈+ ẍcos(θ) − gsin(θ) = 0 (7)

where:
- M = 1.0kg (Cart Mass)
- m = 0.2kg (Pendulum Mass)
- ℓ = 0.5m (Pendulum Length)
- g = 9.81 m
s

⁄ 2 (Gravity Constant)

- θ = 10 degrees = 0.1745 rads (Initial Pendulum Angle)
- θ̇ = 0

rads
s

⁄ 2 (Initial Angular Velocity)

- F = 1.0N (Applied Horizontal Force)

By solving these equations with the assumed variables given this would be used in a classroom setting, we would obtain the following accelerations:
- ẍ= 0.661 m
s

⁄ 2 (Cart Acceleration)

- θ̈= 2.1

rads
s

⁄ 2 (Angular Acceleration)

Meaning that the cart would need to accelerate at a rate of 0.661 m s

⁄ 2 with and angular acceleration of 2.1

rads
s

⁄ 2 on the pendulum to negate an angle of 10 degrees assuming the students applied 1.0 N of force to the pendulum.

These results show that a 1 N horizontal input force produces both forward acceleration of the cart and angular acceleration of the pendulum, demonstrating the system’s sensitivity to small control inputs and the inherent instability that must be managed through active feedback control (e.g., PID or pole-placement design).

This model served as the basis for the initial control simulation and validation of Robot #1’s mechanical and control feasibility.

### 3.4.4 Inverted Pendulum Robot , Reference within Humans – Florence L. Fasugbe

Understanding how an inversed pendulum works in a robot, referencing something that everyone sees every day is a great introduction to it. Humans are a great example of what an inverse pendulum looks like and the actions surrounding self-balance. The ankle within a human act as the wheel axle on a robot that is characterized as the pivot point. The body of a human represents the pendulum or joint of a robot. Lastly, the feet of humans are like the wheels of the robot, which signifies the center of pressure (COP) and the center of mass (COM). The equations (8)

15 | P a g e

and (9) models the idea with concepts of COP [m], COM [kg], angle of the projection plane, gravity [m/s^2]] acceleration [m/s^2]

xG=0.90sin(0.05)≈0.045m (8)

yG=0.90sin(−0.03)≈−0.027m(9)

xG, represent that the COP will change 0.045 cm forward from the COM of the foot and the yG represents that the COP will change –0.027 cm to the left.

## 4 Research and Benchmarking for the Ball-On-Beam Robot

### 4.1 Benchmarking for Ball-On-Beam (Robot 2)

The development of the Ball-on-Beam system is guided by benchmarking against commercial standards, high-end research platforms, and accessible open-source designs. These benchmarks provided the mechanical and control baselines required to achieve a professional-grade outreach tool within a strict sub-$300 budget. The systems selected for system-level comparison include the Acrome Ball and Beam [39], the Microsoft MOAB [40], and the Instructables Arduino Ultrasonic Ball-on-Beam [41]. The Acrome unit serves as the primary commercial benchmark for 1-axis control, while the MOAB highlights the visual spectacle of multi-axis systems. The Instructables project serves as a baseline for low-cost implementation.

### 4.2 System-Level Benchmarking

Table 7: Subleveling Benchmark for Robot 2.

System Reference
Example
Key Features | Relation to Our Concept
Notes / Takeaways

Acrome Ball
and Beam

Acrome
Control
Systems [39]
1-Axis industrial- grade educational platform; integrated PID software. | Establishes the gold standard for 1-axis educational control math.

Retails for $300–$500. Our design matches this
performance for ~$240 while adding untethered battery
power.

Microsoft
MOAB

Project
MOAB
(Microsoft
Bonsai) [40]
2-Axis high-speed balancing platform; utilizes machine teaching and AI. | High-level visual spectacle benchmark for K-12 engagement.

Validates that balancing
systems are highly engaging for outreach, but the 2-axis complexity is too fragile for transport.

Instructables
Ultrasonic
Robot

Arduino Ball
and Beam [41]
Open-source hobby build using ultrasonic sensors and servo-linkage arms. | Low-cost baseline for physical prototyping and early sensor testing.

Highlights the jitter and
inaccuracy of ultrasonic
sensors and mechanical
linkages, driving our move to ToF sensors and direct-drive.

16 | P a g e

### 4.2.1 Distance Sensor Benchmarking

To ensure the PID loop receives accurate data regardless of classroom lighting or surface reflections, the distance sensor was benchmarked against industry-standard hobby alternatives.

Table 8: Sensor benchmark between various sensors to use for robot 2.

Feature / Metric Alternative 1: Ultrasonic
(HC-SR04) [41]

Alternative 2: Resistive
Touch Strip [45]

Selected: VL53L0X Time-of-Flight (ToF) [42]

Detection Method Sound wave reflection (Echo)

| Physical pressure contact | Infrared Laser (Time-of- Flight)

Susceptibility to
Noise
High (affected by wind and temperature) | High (mechanical wear) | Low (isolated from environment)

Environmental
Durability
High | Low (easily damaged by users) | High (contactless and compact)

Measurement
Precision
Low (~3.0 mm) | Medium | High (1.0 mm resolution)

Benchmarking revealed that ultrasonic sensors are too wide-beam for a narrow beam chassis, often catching the edges of the 3D-printed walls. Resistive strips were rejected because K-12 students may damage the physical sensor surface. The VL53L0X ToF sensor [42] was selected because its infrared laser provides precise, point-source data that is unaffected by ambient classroom lighting.

### 4.2.2 Microcontroller Benchmarking

The microcontroller must handle high-speed I2C sensor data, calculate the PID response, and drive a high-torque stepper motor simultaneously.

Table 9: Microcontroller benchmark for comparing various sensor datasets to use for robot 2.

Feature /
Metric

Alternative 1: Arduino Uno (ATmega328P) [41]

Alternative 2: Arduino
Mega 2560 [25]

Selected: Raspberry Pi
Pico (RP2040)
Clock Speed | 16 MHz | 16 MHz | 133 MHz
Processor Type | 8-bit Single-Core | 8-bit Single-Core | 32-bit Dual-Core
Operating Voltage | 5V | 5V | 3.3V (lower power draw)
Cost | ~$20.00 | ~$35.00 | ~$4.00

While the Arduino Uno is common in educational kits, its 8-bit architecture struggles with the floating-point math required for optimized PID loops. The Raspberry Pi Pico was selected for its dual-core architecture, allowing one core to manage the LCD touchscreen UI while the second core handles the high-frequency control loop, all while being the most cost-effective option for mass production.

### 4.2.3 Actuator Benchmarking

The actuation system must provide smooth, high-resolution tilt adjustments without the mechanical play found in

17 | P a g e

plastic gearboxes.

Table 10: Actuator benchmark for comparing various microcontrollers to use for robot 2.

Feature / Metric Alternative 1: SG90 Servo
Motor [23]

Alternative 2: Brushed DC
Motor [36]

Selected: NEMA 17 Stepper
Motor
Control Method | PWM Position Control | PWM Velocity Control | Step/Dir (Pulse Control)
Mechanical Play | High (internal plastic gears) | Very High | Zero (direct-drive shaft)
Angular Resolution | ~1.0 degree | Low | 0.1125 degrees (with 1/8 microstepping)
Torque Stability | Low | Low (requires gearing) | High (constant holding torque)

Standard hobby servos were benchmarked but rejected due to linkage stops the small amount of mechanical play in the plastic arms makes stabilizing a light ping-pong ball nearly impossible. The NEMA 17 Stepper Motor was selected because its direct-drive shaft eliminates linkage arms entirely, and the use of 1/8 microstepping provides the exceptionally fine angular resolution needed to balance the ball smoothly.

### 4.3 Literature Review (Robot 2)

### 4.3.1 Freddy

[23] N. Hammje, “Ball-Balancing Bot Uses OpenCV on a Raspberry Pi to Stop a Ball Dead in Its Tracks,” Hackster.io, 2024. This article showcases a Raspberry Pi-based Ball-on-Plate robot that employs OpenCV for computer-vision tracking and a PID controller to maintain the ball’s position. It provided a clear example of how to couple image feedback with servo actuation for real-time control—insight that guided the team’s Ball-on-Plate concept for Robot #2. The project also demonstrated accessible hardware integration suitable for classroom demonstrations.
[24] J. Sirgado, “Magnet Levitation with Arduino,” Arduino Project Hub, 2022. Sirgado’s tutorial details a low-cost magnetic levitation setup using an Arduino, Hall-effect sensor, and PID loop. It served as the foundation for our Magnetic Levitation Robot concept by illustrating the nonlinear relationship between magnetic force and coil current and showing how proportional–integral–derivative tuning can stabilize an otherwise unstable equilibrium.
[25] “Wheelbot: A Symmetric Unicycle That Balances Using Reaction Wheels,” TechXplore, 2022. This article describes a unicycle robot stabilized solely by reaction wheels, validating the feasibility of small-scale momentum-exchange stabilization. The system’s use of multiple flywheels and IMU feedback informed our Reaction Wheel Robot design, which uses the same torque-generation principle to resist external disturbances.
[26] A. Md. K. Alam, M. R. Karim, and S. M. M. Hasan, “Stabilising a cart inverted pendulum system using pole placement control method,” Proc. 3rd Int. Conf. on Electrical Information and Communication Technology (EICT), Khulna, Bangladesh, 2017, pp. 1–6, doi: 10.1109/EICT.2017.8168481.
[27] D. J. Block, K. J. Åström, and M. W. Spong, The Reaction Wheel Pendulum, Morgan & Claypool Publishers, 2007. A fundamental text on reaction-wheel dynamics, this reference introduces nonlinear and linearized equations of motion and details feedback control for underactuated systems. Its derivations directly supported our torque and angular-acceleration calculations for the Reaction Wheel Robot prototype.

18 | P a g e
[28] R. Gajamohan, M. Muehlebach, T. Widmer, and R. D’Andrea, “The Cubli: A Cube That Can Jump Up and Balance,” in IEEE/RSJ Int. Conf. on Intelligent Robots and Systems (IROS), 2013. The Cubli project is a three-axis reaction-wheel cube that balances and even jumps upright. Its control architecture and hardware selection were used as a high-fidelity benchmark for our design feasibility and scaling analysis.
[29] J. R. Wertz, Spacecraft Attitude Determination and Control, Springer, 1978. Wertz’s classical text provided theoretical grounding on momentum-exchange and attitude control. Though focused on spacecraft, the same principles of internal torque exchange and stability margins apply to our Reaction Wheel Robot, offering insight into wheel-sizing and damping.
[30] B. Wie, Space Vehicle Dynamics and Control, 2nd ed., AIAA, 2008. Wie’s modern treatment of control dynamics supplemented Wertz by discussing closed-loop response and actuator saturation limits. These concepts guided our controller-gain selection and maximum-speed constraints for safe educational use.
[31] University of Michigan, “Ball & Beam: System Modeling,” Control Tutorials for MATLAB and Simulink (CTMS). Provides mathematical modeling and linearization of unstable systems such as the ball-and-beam setup, used as a foundation for the pendulum model.
[32] B. Cazzolato, “Derivation of the Dynamics of the Ball and Beam System,” Univ. of Adelaide, School of Mechanical Engineering. Presents detailed nonlinear dynamic equations for the ball-and-beam system that supported pendulum equation derivations.
[33] K. C., “Inverted Pendulum: Control Theory and Dynamics,” Instructables, 2025. A simplified tutorial connecting theoretical control design to hobby-scale implementation.
[34] S. Sackett, “Self-Balancing Inverted Pendulum Robot,” Shay Sackett’s Project Portfolio. Independent project documenting the design process and challenges of building a two-wheel self-balancing robot.
[35] B. T. Williams, “Self-Balancing Robot Using PID Packs Other Punches,” Elektor Magazine, Oct. 5, 2022. A detailed description of modern implementations of self-balancing robots using PID control.
[36] “DC Motor Speed: System Modeling,” Control Tutorials for MATLAB and Simulink (CTMS). Explains motor dynamics and transfer functions with MATLAB representation, helping link pendulum control equations to actuator behavior.
[37] “Ball and Beam: System Modeling (CTMS).” Illustrates comparable unstable control systems and feedback-control concepts that inspired our pendulum work.
[38] S. Anand and R. Prasad, “Dynamics and control of ball and beam system” This paper analyzes the unstable dynamics of the classic Ball-on-Beam system and derives the torque and motion equations required to maintain balance. Its discussion of gravitational loading, moment arms, and actuator sizing directly informed our motor torque calculations for Robot #2. This reference supported the justification for selecting NEMA-17 stepper motors with sufficient torque margin and reinforced the need for a safety factor in actuator sizing.
[39] Acrome, “Ball and Beam,” Acrome Control Systems, 2024. [Online]. Available: https://acrome.net/product/ball-on-beam. [Accessed: April 19, 2026]. The Acrome Ball and Beam system serves as the primary commercial and educational benchmark for 1-axis control robotics. This system is heavily utilized in university-level control laboratories to teach fundamental PID and State-Space control theories. Reviewing this

19 | P a g e

system validated the decision to focus on a 1-axis track for K-12 education, as it provides the most direct, observable translation of feedback loop mathematics. Furthermore, the Acrome system retails between $300 and $500, establishing a baseline commercial cost. This benchmark directly informed the team’s constraint to achieve equivalent 1-axis performance utilizing 3D-printed chassis components to keep the per-unit reproduction cost under $300.

[40] Microsoft, “Project Moab,” Microsoft Autonomous Systems, 2024. [Online]. Available: https://www.microsoft.com/en-us/ai/bonsai-moab. [Accessed: April 19, 2026]. Project MOAB, developed by Microsoft Bonsai, represents the high-end "spectacle" benchmark for balancing systems. MOAB utilizes a 3-axis parallel robot (Stewart platform) combined with machine teaching to balance a ball on a flat plate. While the visual engagement of this system is exceptionally high for outreach purposes, reviewing the MOAB architecture highlighted severe vulnerabilities for K-12 fleet deployment. The requirement for three perfectly synchronized actuators, complex spatial mathematics, and fragile linkage arms informed our team's FMEA and justified the physical pivot away from a Ball-on-Plate design to the much more durable and mass-producible 1-axis Ball-on-Beam system.
[41] “Arduino Ball and Beam PID Controller,” Instructables, 2020. [Online]. Available: https://www.instructables.com/Arduino-Ball-and-Beam-PID-Controller/. [Accessed: April 19, 2026]. To understand the limitations of low-cost, open-source educational robotics, the team analyzed standard Instructables-level Arduino Ball and Beam projects. These projects typically utilize an HC-SR04 ultrasonic sensor and a standard SG90 plastic-gear servo. Reviewing these systems revealed critical mechanical and signal flaws: ultrasonic sensors suffer from wide-beam echo interference off the beam walls, and servo linkages introduce significant mechanical backlash (slop). This literature directly influenced the physical redesign of our system, prompting the upgrade to targeted laser-based Time-of-Flight sensing and direct-drive stepper actuation to eliminate the jitter observed in these baseline models.
[42] STMicroelectronics, “VL53L0X: World's smallest Time-of-Flight ranging and gesture detection sensor,” STMicroelectronics Datasheet, 2024. [Online]. Available: https://www.st.com/en/imaging-and-photonics-solutions/vl53l0x.html. (https://www.st.com/en/imaging-and-photonics-solutions/vl53l0x.html) [Accessed: April 19, 2026]. To solve the signal scattering issues identified in early prototypes, the team researched the STMicroelectronics VL53L0X sensor. The manufacturer’s technical specifications confirm the sensor utilizes a 940nm vertical-cavity surface-emitting laser (VCSEL) to calculate distance based on photon travel time, rather than relying on sound wave reflection or physical contact. The datasheet validates that this sensor provides 1.0 mm resolution and remains highly immune to ambient lighting conditions. This literature justified the sensor's selection, ensuring the PID loop would receive accurate, noise-free distance data regardless of the K-12 classroom lighting environment.
[43] Raspberry Pi Ltd, “Raspberry Pi Pico Documentation,” Raspberry Pi Microcontrollers, 2024. [Online]. Available: https://www.raspberrypi.com/documentation/microcontrollers/raspberry-pi-pico.html. [Accessed: April 19, 2026]. The control architecture requires rapid, continuous calculations without stalling the physical motor actuation. Literature regarding the Arduino Uno (ATmega328P) revealed an 8-bit, 16 MHz limitation that struggles with simultaneous I2C polling and high-frequency motor stepping. Researching the Raspberry Pi Pico (RP2040) documentation revealed a 32-bit, 133 MHz dual-core architecture. This specification literature was critical for the project, as it proved the RP2040 possessed the hardware necessary to isolate the sensor-reading loop onto Core 0 and the motor-driving PID loop onto Core 1, eliminating the latency bottlenecks found in standard 8-bit microcontrollers.

20 | P a g e

### 4.3.2 Florence

[44] 井手隆統, 本田功輝, 金田礼人, 中島康貴, and 山本元司, “Comparison of CoP estimation and center-of-gravity sway measurement in human standing posture using inertial sensors,” Dissertation, Kyushu Univ. Grad. Sch. Eng., Fukuoka, Japan.
-Annotation: Focuses on studying the aspects of measuring standing movement with sensors and how the sensors are affected by swaying while standing for a long period of time. Center for Pressure (COP) of humans using sensors to analyze gait patterns.
[45] S. Sasagawa, J. Ushiyama, M. Kouzaki, and H. Kanehisa, “Effect of the hip motion on the body kinematics in the sagittal plane during human quiet standing,” Neurosci. Lett., vol. 450, no. 1, pp. 27–31, Jan. 2009, doi: 10.1016/j.neulet.2008.11.027.
-Annotation: Standing affects the hip motion due to the center of mass; COM.
[46] J. L. Cabrera and J. G. Milton, “Human stick balancing: Tuning Lèvy flights to improve balance control,” Chaos, vol. 14, no. 3, pp. 691–698, Sep. 2004, doi: 10.1063/1.1785453.
-Annotation: Concept of stabilization of rapid human movements which is determined by equilibrium and limit cycles with motor controls analysis like closed loop control; automatic control systems.
[47] B. Sprenger, L. Kucera, and S. Mourad, “Balancing of an inverted pendulum with a SCARA robot,” IEEE/ASME Trans. Mechatronics, vol. 3, no. 2, pp. 91–97, Jun. 1998, doi: 10.1109/3516.686676.
-Annotation: Balancing an inverted pendulum with a robotic manipulator is a benchmark problem requiring precise sensing and compensation for nonlinear effects like friction, backlash, and elasticity.
[48] Winkler and J. Suchý, “Erecting and balancing of the inverted pendulum by an industrial robot,” IFAC Proc. Volumes, vol. 42, no. 16, pp. 323–328, 2009, doi: 10.3182/20090909-4-jp-2010.00056.
-Annotation: Inverted pendulum on an industrial robot by using one algorithm to swing it up and a state-space controller with offset adaptation to balance it.
[49] Y. Y. Lim, C. L. Hoo, and Y. M. Felicia Wong, “Stabilizing an inverted pendulum with PID controller,” MATEC Web Conf., vol. 152, p. 02009, 2018, doi: 10.1051/matecconf/201815202009.
-Annotation: Stabilizing an inverted pendulum with a reaction wheel and a PID (Proportional Integral Derivative) controller is simulated to balance it effectively and efficiently.

[50]” D. Zhang, J. Wang, H. Zhang, and L. Yu, “Research on inverted pendulum control system based on vision sensor,” in Proc. ICMLCA 2021: 2nd Int. Conf. Mach. Learn. Comput. Appl., Shenyang, China, 2021, pp. 1–5. -Annotation: Vision-based control system for an inverted pendulum, using OpenCV to calculate its deflection angle and verify effective stabilization without relying on encoder sensors.

[51] A. Kastner, J. Inga, T. Blauth, F. Kopf, M. Flad, and S. Hohmann, “Model-based control of a large-scale ball-on-plate system with experimental validation,” KITopen Repository, Karlsruhe Inst. Technol., Mar. 2019, doi: 10.1109/icmech.2019.8722850.
-Annotation: Development of system dynamics model using Lagrange and the Euler method to analyze the frequency domain to create state-feedback control to ensure stability of a system.
[52] Sudha Ellison Mathe, Hari Kishan Kondaveeti, Suseela Vappangi, Sunny Dayal Vanambathina, and Nandeesh

21 | P a g e

Kumar Kumaravelu, “A comprehensive review on applications of Raspberry Pi,” Computer science review, vol. 52, pp. 100636–100636, May 2024, doi: https://doi.org/10.1016/j.cosrev.2024.100636.
-Annotation: Understanding the concept of how Raspberry Pi is integrated into machine learning and experimentation.
[53] A. S. Silva, R. M. Cotta, and L. A. Ismail, “Uncertainty analysis of infrared thermography in convective heat transfer,” ResearchGate, 2014. [Online]. Available: https://www.researchgate.net/publication/265540159_Uncertainty_Analysis_of_Infrared_Thermography_in_Convective_Heat_Transfer (https://www.researchgate.net/publication/265540159_Uncertainty_Analysis_of_Infrared_Thermography_in_Convective_Heat_Transfer)
-Annotation: Analysis of the uncertainty of the sensor's thermal radiation through temperature measurement with an infrared camera.

### 4.4 Mathematical Modeling (Robot 2)

### 4.4.1 Dynamic Physical Limits – Freddy Rivera

To ensure the physical system remains mathematically controllable during K-12 outreach demonstrations, the dynamic limits of the ping-pong ball were modeled using fundamental Lagrangian mechanics [1]. The foundational plant model dictating the ball's linear acceleration (ẍ) relative to the beam's angle (θ) and angular velocity (θ̇) is defined by the following energy balance equation:
(

Jb
R² +m) ẍ− mxθ̇² + mgsin (θ) = 0

(10)

where Jb =

2
3

mR

2 = 7.20 × 10⁻⁷kg·m² is the mass moment of inertia of a thin hollow sphere, m = 0.0027kg is

the mass of a standard ping-pong ball, R = 0.020m is the ball's radius, and g = 9.81m/s² is standard gravitational acceleration. Because the system's operational geometry restricts the tilt angle to small values, the small-angle approximation (sin θ ≈ θ) was applied. Assuming negligible centrifugal acceleration at low rotational speeds (θ̇ ≈ 0), the plant simplifies to the primary kinematic relationship governing ball motion, where the 3/5coefficient explicitly accounts for the rolling inertia of a thin hollow sphere [38]:

ẍ= −

3
5

gθ

(11)

With the baseline plant established, a critical failure condition was modeled to determine the system's safe operating envelope. If the downward rotational acceleration of the beam exceeds gravitational acceleration, the normal contact force between the ball and beam surface reduces to zero, causing the ball to physically separate from the tracking surface. The tangential acceleration at the furthest active rolling edge of the beam (r = 0.1454 m, representing the maximum physical travel distance from the center pivot to the end-wall) must therefore not exceed g = 9.81m/s². The theoretical maximum angular acceleration was calculated as:

θ̈max =

g
r

=

9.81 m/s²
0.1454 m

= 67.47 rad/s²

(12)

22 | P a g e

This result establishes the absolute physical boundary of the system: angular accelerations exceeding this threshold will cause measurable tracking failure. Defining this ceiling allowed the team to design the 3D-printed chassis with geometric hard-stops at ±20°, ensuring the stepper motor can never mechanically approach this theoretical failure point during operation.

### 4.4.2 Control System Architecture – Freddy Rivera

To establish baseline control logic for the direct-drive stepper motor, the Ball-on-Beam system was modeled as a closed-loop continuous-time system. Using standard linearization and pole-placement techniques [2], the team derived theoretical baseline gains for a Proportional-Integral-Derivative (PID) controller.

The model was constrained by targeted educational performance specifications: a settling time of Ts = 2.0s and an overshoot of less than 5%, which together yield a natural frequency of ωn = 2.83 rad/s. Matching the closed-loop characteristic equation to the target polynomial produced the following expression:

s

3 + 5.886Kds

2 + 5.886Kps + 5.886Ki = 0 (13)

The resulting theoretical baseline gains are summarized in Table 12 below.

Table 11: Theoretical PID baseline gains derived from pole-placement targeting TS = 2.0 and overshoot < 5%.

Gain | Parameter Theoretical Value
Proportional | Kp | 14.95
Integral | Ki | 27.18
Derivative | Kd | 4.08

While this continuous-time model validates theoretical system stability, two physical non-idealities precluded direct implementation of these values. First, discrete sampling latency inherent to the VL53L0X Time-of-Flight sensor introduces phase lag not captured by the continuous model. Second, surface friction between the ping-pong ball and the 3D-printed PLA beam introduces nonlinear damping that varies with ball velocity. Accordingly, the calculated gains serve strictly as an architectural starting point, with final system stabilization achieved through empirical tuning within the microcontroller's software loop.

### 4.4.3 Dynamics of the Beams Structure with - Florence L. Fasugbe

To prevent the ball from losing contact with the beam due to inertial effects, a conservative upper bound on angular acceleration was imposed by requiring gravitational acceleration to dominate:

rmax|θ̇| < g (14)

Rearranging and substituting:
|θ̇|max
≈

g

rmax

=

9.81
0.127

≈77 rad
s

2

(15)

23 | P a g e

This value defines the maximum beam angular acceleration that should be enforced during controller tuning to ensure ball retention.

For comparison, the motor-limited angular acceleration is:

θmax,motor ̇ | ≈

τmax

Jtotal

(16)

which are several orders of magnitude larger than the safe bound. Therefore, beam acceleration will be limited in software rather than by motor capability.

Maximum Recoverable Beam Angle (Load Case 3)
The angle of the beam determines how much the ball will still roll without slipping. The controller will help determine this predictability based on the linear system being incorporated. Friction determined this and if the angle is too large, the ball friction will exceed that limit, and the ball will start to slip drastically [5].

Minimum friction for rolling to occur:

Ff,min=25mgsinθ (17)

Maximum friction for rolling to occur:

Ff,max=μsmgcosθ (18)
Ff,max=μsmgsinθ. (19)

The coefficient of static friction (μsμs) shows how much contact there will be between the surface of the beam and ball. By canceling the like terms from the two equations above and ordering them in this form Ff,mi≤Ff,max, the result of that will be:

θmax=arctan(52μs) (20)

The ping pong’s friction on smooth PLA is low with approximately 0.15. Plugging in the values into Equation (12) the degree maximum will be:

θmax = arctan (52(0.15)) ≈ 0.357 radθ max = arctan⁡520.15 ≈ 0.357 rad (21)

0.357 rad⋅180π ≈ 20.5° 0.357 rad⋅180π ≈20.5°

Anything below that angle of 20.5° the ball will not slip, but anything above that the ball will experience sliding, and the motor will have difficulty adjusting the ball at a certain point.

24 | P a g e

## 5 Design Concepts for the Inverted Pendulum Robot

### 5.1 Functional Decomposition

Fig. 2. Process Diagram for Robot 1

The functional decomposition chart above illustrates the primary actions our inverted pendulum system must execute to maintain dynamic stability. Rather than looking at the physical hardware, this model tracks the flow of data and energy through the system's closed-loop control cycle.

For this specific project, mapping these functions is critical because the robot's success relies entirely on minimizing latency between the "Sense," "Process," and "Actuate" functional blocks. The system must continuously convert the physical orientation of the U-shaped pendulum into magnetic field variations (sensing), process that data to compute an error-correction signal (processing) via PID controller and convert electrical energy from the batteries into kinetic energy at the wheels (actuating) fast enough to overcome gravity. If any functional block lags or fails, the entire system loses equilibrium.

### 5.2 Concept Generation

During the early stages of the design process, several top-level architectural concepts were generated to solve the problem of balancing an inverted pendulum. The concepts were evaluated based on mechanical complexity, stability, and control feasibility. Below are the primary top-level concepts considered. To generate concepts for the frame design of the pendulum robot, each team member created a sketch of a potential design that was then evaluated based on their ability to satisfy the customer requirements pertaining to the frame.

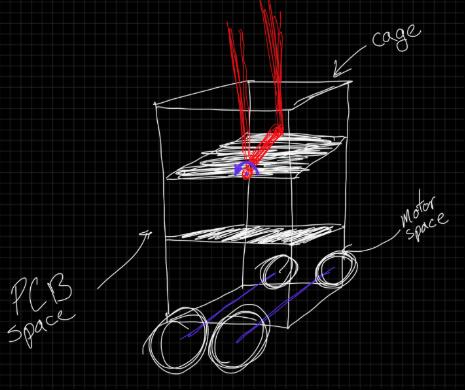
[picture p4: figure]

Fig. 3. Concept 1

The first concept for the pendulum robot frame is a vertical frame design, with multiple layers to facilitate

25 | P a g e

better component organization, and additionally features a double pendulum structure on a singular axis. This concept features an organized structure to the frame, and a more aesthetically appealing design as the outer frame could be customized to resemble a traditional robot. The cons of this concept are the less stable structure due to the increased vertical height, and the additional expenses of the larger frame.

In this concept, the entire chassis of the robot acts as the pendulum, balancing on two coaxial wheels. The brain and battery are housed in the vertical body. The pros of this frame are its simple and streamlined design, having less components and therefore costs. The cons of this design are the more complicated math and programing required for a 2-wheel pendulum robot, falling when powered off (dangerous around an audience), and reduced structural integrity of the frame.

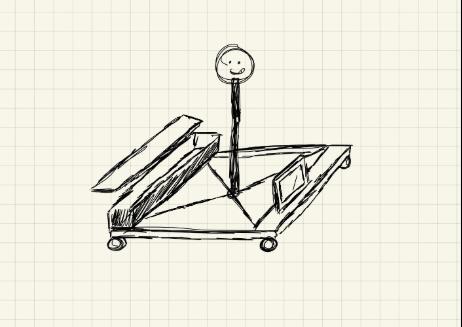
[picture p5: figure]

Fig. 4. Concept 2

The 4-wheel cart design is shown with a rear compartment for the robot components, and a large, centered pendulum in the frame. On the front of the cart is a touch screen for user interaction. The pros of this frame are the simplicity of the frame itself, the stable design, and more organized back compartment. The cons of this design are in its larger size and operating space requirement.

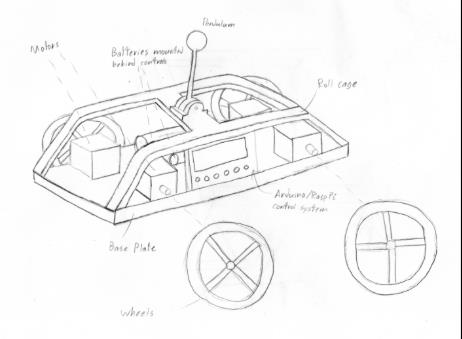
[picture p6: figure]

Fig. 5. Concept 3

This concept for the pendulum robot frame is a more streamlined angular frame to help sustain impacts from the fall test. On top of the central cross beam is the pendulum structure, and on the side is where the interactive element

26 | P a g e

would be placed. Pros include better aesthetics and a compact electronic interior. The cons are lower center of gravity leading to needing a larger pendulum arm and a more difficult organizing components.

Following the evaluation of these concepts, the team selected a hybrid approach leaning heavily on Concept 1. By utilizing a 4-wheel cart base, the robot safely satisfies the requirement to not fall over when powered off, protecting the audience and internal electronics. While it requires a larger operating footprint, it allows for the integration of our U-shaped pendulum arm and provides the necessary stability for K-12 interactive elements. Features from Concept 4 (such as reinforced, impact-resistant angular geometry) will be integrated into the final 3D-printed chassis to ensure it survives the required 34-inch drop test.

### 5.3 Selection Criteria

The final component selection was verified against the following quantifiable metrics to ensure the robot meets the "State-of-the-Art" benchmarks. The concepts were evaluated against a set of weighted criteria derived from the project’s engineering requirements. To ensure a successful demonstration for K-12 students, the following metrics were prioritized:

1. Dynamic Stability: The ability to recover from a 45-degree tip without human intervention.
2. Structural Durability: Calculated Factor of Safety (FoS) must be > 2.0 during a 40-inch drop impact.
3. User Interactivity: The inclusion of accessible interfaces (e.g., touch screens or drawing paths).
4. Component Integration: Availability of mounting points for the RP2040 and the axis-mounted magnetic encoder.

Angular Resolution (The AS5600 Encoder)

- Metric: 12-bit Resolution (2

12 = 4096 positions per 360° ).
- Discussion: The AS5600 was selected because it provides an angular resolution of 0.087° . This high precision is necessary to detect the "micro-falls" of the pendulum arm before they become visible to the human eye, allowing the PID loop to initiate corrective motor torque sooner. This significantly outperforms the 8-bit resolution found in standard consumer-grade potentiometers. Additionally, if the robot is bumped or the power flickers, the sensor instantly knows exactly where the arm is without needing to "re-home" or calibrate.

Computational Throughput (The RP2040)

- Metric: 133 MHz Dual-Core ARM Cortex-M0+.
- Discussion: The RP2040 (Raspberry Pi Pico) was chosen over standard 8-bit microcontrollers (like the ATmega328P) specifically to handle the high-speed I2C communication required by the AS5600 and the floating-point math required for the PID algorithm. One core is dedicated to the Sense function (polling the encoder), while the second core handles Actuation (PWM generation), eliminating "jitter" in the motor response.

Power Density & Safety (LiFePO4 32700 Batteries)

- Metric: 3.2V Nominal per cell; High Discharge Rate.
- Discussion: Although LiFePO4 32700 cells are less common in the current market, they were selected for

27 | P a g e

their Safety Profile and Cycle Life. Unlike standard Li-ion (cobalt-based) batteries, LiFePO4 is chemically stable and significantly less prone to thermal runaway, which is a critical "Audience Safety" requirement for K-12 demonstrations. The high discharge capability ensures the 520 Motors can draw the required 4A stall current without a significant voltage drop that would reset the RP2040.

By combining these components into the 4-wheel cart design, we can ensure high and repeated performance:

- Mechanical Choice: The 520 L-Type motors provide 10kg·cm of torque, which, when paired with the 12-bit precision of the AS5600, creates a highly responsive system.
- Hardware Integration: The RP2040 acts as the bridge. It processes the 0.087° changes from the encoder and translates them into PWM signals for the motors.
- Factor of Safety: The use of LiFePO4 batteries provides an electrical Factor of Safety. Even if the motors stall (drawing maximum power), the battery chemistry is stable enough to prevent overheating in a classroom environment.

### 5.4 Concept Selection

A Pugh Chart was utilized to compare the four concepts. Concept 1 (The 4-Wheel Cart) emerged as the superior design primarily due to its inherent stability when powered off and the physical space available for interactive components. While the 4-wheel design increases the BOM (Bill of Materials) cost, the trade-off for audience safety and ease of sensor mounting was deemed necessary.

Table 12. Final Pugh Chart for Robot 1
Criteria Weight Concept 2
(2-Wheel)

Concept 4
(Angular)

Selected: 4-Wheel
Cart
Stability (Static) | 25% | 1 (Falls) | 4 | 5 (Extremely Stable)
Sensing Precision | 20% | 3 | 4 | 5 (Direct Axis Mount)
Impact Resilience | 20% | 2 | 5 | 4 (Reinforced Chassis)
K-12 Interactivity | 15% | 2 | 3 | 5 (Space for Screen)
Complexity/Cost | 20% | 5 | 3 | 2 (More Parts/Motors)
Weighted Total | 100% | 2.65 | 3.95 | 4.35

The final selected concept is a 4-wheeled cart utilizing a centralized, U-shaped pendulum arm. This configuration was chosen specifically to facilitate the mounting of the AS5600 Magnetic Encoder directly onto the axis of rotation, providing 12-bit angular feedback without the signal noise associated with body-mounted IMUs.

The chassis is 3D-printed in PLA with a 20% gyroid infill to satisfy the Impact Resilience requirement established by Colin’s fall-test modeling. To drive the system, four L-type 520 reduction motors are mounted in a "flat" configuration to maintain a low center of gravity, powered by a 2S LiFePO4 32700 battery array.

Table 13. Factor of Safety Summary for Robot 1

Component / Sub-System

| Failure Mode | Calculation Basis | Calculated FoS
Main Chassis (PETG) | Structural Fracture 40-inch Drop Impact Force (Favg) | 2.2
Pendulum Arm Axis | Shear of Axis Pin | Peak Torque from 520 Motors | 3.5

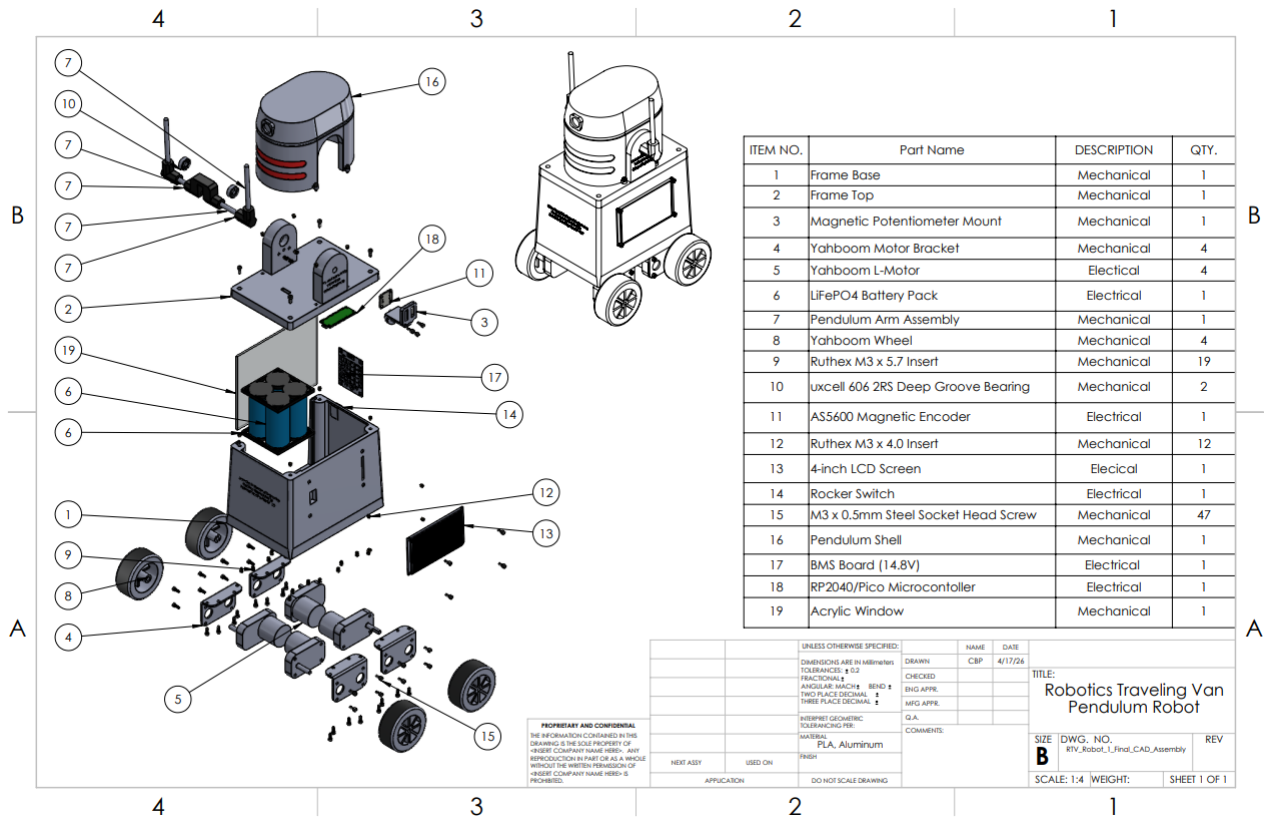
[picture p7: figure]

28 | P a g e
LiFePO4 Batteries | Thermal Overload | 4A Stall Current vs. Max Discharge | 1.8
Motor Drivers | Overcurrent | Driver Rated Amperage vs. Stall Current | 1.4
RP2040 (Pi Pico) | Control Instability | Loop Frequency vs. Pendulum Falling Rate | 4.0

The FoS table serves as the final justification for our "over-engineered" components. Specifically, the Control System FoS of 4.0 highlights the advantage of the RP2040; by running the PID loop four times faster than the pendulum's natural frequency, we eliminate the risk of "processing lag" causing a fall.

Furthermore, the Chassis FoS of 2.2 validates our material selection of PLA because it is easier to print, and sufficient at high infills to ensure the robot survives the critical 34-inch drop test requirement without catastrophic frame failure. Collectively, these safety factors confirm that the selected concept is a robust, "state-of-the-art" solution for an interactive educational environment.

Fig. 6. Inverted Pendulum Final Design

## 6 Design Concepts for the Ball on Beam System

### 6.1 Functional Decomposition

The functional decomposition of the Ball-on-Beam system is visualized in Figure X via a continuous closed-loop process diagram. The system initiates with the primary energy flow, powering the NEMA 17 stepper motor and establishing the zero-point axis. Once initialized, the system enters the "Continuous Balance Loop," which governs the primary signal and material flow of the robot. The VL53L0X Time-of-Flight sensor captures the physical

29 | P a g e

distance reading of the ping-pong ball, passing that signal to the microcontroller. The controller processes the error via the PID algorithm to compute the required beam angle correction, which then triggers the stepper motor to physically tilt the beam, physically altering the ball's position before looping back to the sensor.

Developing this functional decomposition was critically important for the Ball-on-Beam project because it visually isolated the software logic from physical actuation. By mapping the system as a continuous loop, the team was able to identify latency bottlenecks—specifically recognizing that the sensor polling rate (Sense) and the mechanical micro-stepping (Activate) needed to occur simultaneously on separate processing cores to prevent the control loop from stalling during physical demonstrations.

Fig. 7. Process Diagram for Robot 2

### 6.2 Concept Generation

During the early stages of the design process, several top-level architectural concepts were generated to achieve the educational goal of demonstrating active feedback control. The concepts were evaluated based on mechanical complexity, durability, and cost feasibility to meet the strict sub-$300 budget. To generate concepts for the balancing system, the team evaluated multiple architectures. The primary applicable concepts evaluated for the final physical build are detailed below.

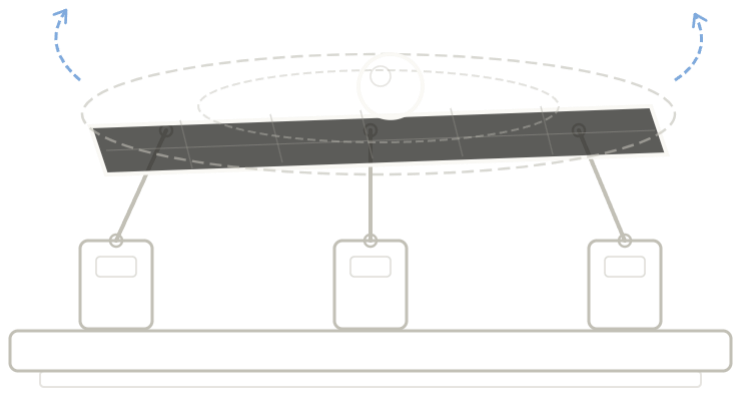
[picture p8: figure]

Fig. 8. Concept 1 (2-Axis Ball-on-Plate)

The first concept is a 2-Axis Ball-on-Plate (Gimbal System) that utilizes a flat plate manipulated by multiple servo motors and linkage arms to balance a ball in a two-dimensional plane (X and Y axes). The pros of this design are that it is highly interactive and visually spectacular for K-12 audiences, allowing for omnidirectional path-tracking. The cons of this concept are the extremely high mechanical complexity, the massive fracture risk posed by the fragile linkage arms during transport, and the high processing power and component costs that severely threatened the budget limit.

30 | P a g e

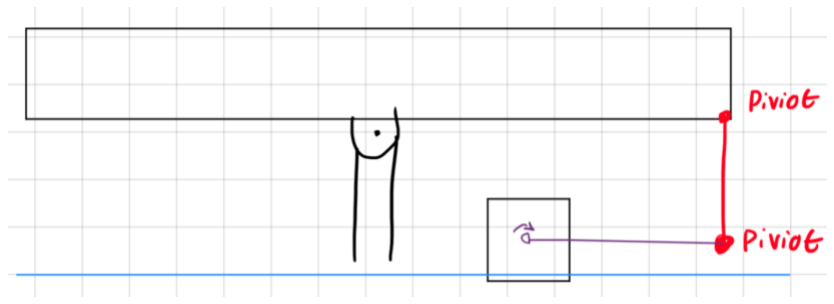
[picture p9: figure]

Fig. 9. Concept 2 (Servo-Driven Linkage Ball-on-Beam)

The second concept is a Servo-Driven Linkage Ball-on-Beam. This concept simplifies the system to a 1-axis beam (X-axis only) but utilizes a standard hobby servo attached to an offset linkage arm to push and pull the beam on a stationary hinge. The pros of this frame are its exceptionally low cost, utilization of standard off-the-shelf hobby components, and highly documented presence in open-source educational kits. The cons of this design are the high mechanical slop from plastic gears and physical "play" at the linkage joints, which introduces severe backlash and makes maintaining a smooth, perfectly still PID balance nearly impossible.

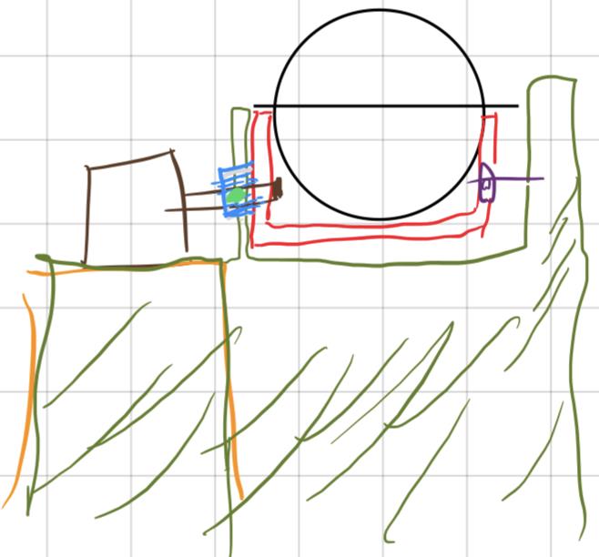
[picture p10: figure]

Fig. 10. Concept 3 (1-Axis Direct-Drive Ball-on-Beam)

This concept is a 1-Axis Direct-Drive Ball-on-Beam. It maintains the 1-axis educational focus but completely eliminates linkage arms by mounting the center of the beam directly onto the drive shaft of a high-resolution NEMA 17 stepper motor. The pros of this design include zero mechanical backlash, geometrically symmetrical control logic, and high structural durability due to the elimination of external moving arms. The cons are the requirement for more complex software implementation, specifically the need for 1/8 micro-stepping to ensure the stepper motor actuates smoothly without shaking the ball.

Following the evaluation of these concepts, the team selected Concept 3 (1-Axis Direct-Drive Ball-on-Beam). By utilizing a direct-drive stepper motor, the robot safely satisfies the requirement for high structural rigidity during transport and eliminates the mechanical jitter that plagues cheaper models. While it requires a more advanced

31 | P a g e

software architecture, it allows for the integration of our Time-of-Flight sensor and provides the necessary stability for K-12 interactive demonstrations without exceeding the $300 budget limit.

### 6.3 Selection Criteria

The final component selection was verified against the following quantifiable metrics to ensure the robot meets the "State-of-the-Art" benchmarks. The concepts were evaluated against a set of weighted criteria derived from the project’s engineering requirements. To ensure a successful demonstration for K-12 students, the following metrics were prioritized:

1. Dynamic Stability: The physical system must prevent the ball from launching off the track under maximum motor acceleration.
2. Structural Rigidity: Calculated Factor of Safety (FoS) must be > 2.0 to withstand maximum rotational stall torque against the geometric hard-stops.
3. Untethered Runtime: The system must run continuously on battery power for > 90 minutes without voltage brownouts.
4. Actuation Resolution: The motor must be capable of sub-degree adjustments to eliminate ball oscillation (jitter).

Spatial Resolution (The VL53L0X ToF Sensor)

- Metric: 1.0 mm linear tracking resolution via 940nm infrared laser.
- Discussion: The VL53L0X was selected because it utilizes a highly focused Time-of-Flight laser, providing a strict 1.0 mm resolution. This high precision is necessary to detect millimeter-level deviations of the ping-pong ball from the center setpoint. This significantly outperforms standard HC-SR04 ultrasonic sensors, which utilize sound waves that scatter against the 3D-printed side walls of the beam and create false readings.

Angular Resolution (NEMA 17 Stepper & 1/8 Micro-Stepping)

- Metric: 0.225° rotational resolution per step.
- Discussion: Standard hobby servos possess inherent backlash (slop) in their plastic gears, usually resulting in ~1.0° of mechanical play. By selecting a NEMA 17 Stepper motor and utilizing a stepper driver set to 1/8 micro-stepping (1.8° / 8), the system achieves a highly precise 0.225° angular resolution. This allows the PID loop to make microscopic angle adjustments, keeping the ball perfectly still and eliminating the mechanical jitter found in lower-tier benchmarks.

Computational Throughput (The RP2040)

- Metric: 133 MHz Dual-Core ARM Cortex-M0+.
- Discussion: The RP2040 (Raspberry Pi Pico) was chosen over standard 8-bit microcontrollers specifically to handle the high-speed I2C communication required by the ToF sensor and the floating-point math required for the PID algorithm. One core is dedicated to the Sense function (polling the laser), while the second core handles Actuation (calculating PID and sending step pulses), eliminating processing latency.

By combining these components into the 1-axis direct-drive design, we can ensure high and repeated performance:

- Mechanical Choice: The direct-drive configuration eliminates linkage arms entirely, creating zero-backlash torque transfer.

32 | P a g e
- Hardware Integration: The RP2040 acts as the bridge. It processes the 1.0 mm changes from the ToF sensor and translates them into hyper-precise 0.1125° stepper pulses.
- Factor of Safety: The use of a 14.8V LiFePO4 battery array paired with a dedicated buck converter provides an electrical Factor of Safety, ensuring the logic voltage remains perfectly stable even when the NEMA 17 is drawing its maximum holding torque.

### 6.4 Concept Selection

A Pugh Chart was utilized to compare the three primary concepts generated in the Concept Generation section. Concept 3 (The 1-Axis Direct-Drive) emerged as the superior design primarily due to its inherent mechanical rigidity and high sensing precision. While the 2-Axis Gimbal provided higher visual spectacle, the trade-off in transport durability and budget compliance made the 1-axis direct-drive the necessary selection.

Table 14. Final Pugh Chart for Robot 2

Criteria | Weight | Concept 1 (2-Axis Gimbal)

Concept 2
(Servo-Linkage)

Selected: Direct-Drive Beam

Stability (Dynamic) | 25% | 2 (Highly complex) | 2 (Slop/Jitter) | 5 (Highly Stable)
Sensing Precision | 20% | 4 | 2 | 5 (ToF Laser)
Structural Rigidity | 20% | 1 (Fragile arms) | 3 | 5 (Solid Direct Mount)
Complexity / Cost | 15% | 1 (Over $300 limit) | 5 (Very Cheap) | 4 (Within Budget)
K-12 Interactivity | 20% | 5 (Omni-directional) | 3 | 4 (Highly Accessible)
Weighted Total | 100% | 2.35 | 2.80 | 4.65

The final selected concept is a 1-axis Ball-on-Beam system utilizing a centralized, symmetrical pivot. This configuration was chosen specifically to facilitate mounting the beam directly to the D-shaft of the NEMA 17 stepper motor, eliminating mechanical linkage arms entirely and allowing for pure angular torque transfer with 0.225 degree precision.

The chassis is 3D-printed in PLA with heavily reinforced 16.94 mm wall thicknesses and heat-set threaded inserts to satisfy the Structural Rigidity requirement during van transport. The base additionally features physical geometric hard-stops at +/-20 degrees to serve as a mechanical failsafe against software malfunction, ensuring the beam can never exceed the safe angular acceleration threshold under any operating condition.

Table 15. Factor of Safety Summary for Robot 2

Component /
Sub-System
Failure Mode | Calculation Basis | Calculated FoS

Main Chassis
(PLA)
Hard-Stop Fracture | Motor Stall Torque vs. 20% Infill PLA Yield Strength | 2.5

33 | P a g e
Dynamic Geometry | Ball Liftoff (Loss of Contact) | Software-Limited Angular Acceleration vs. Gravitational Dominance Threshold (33.7 vs 67.47 rad/s²) | 2.0
Battery Array | Power Depletion | Theoretical Runtime vs. 90-Minute Requirement (288 min vs. 90 min) | 3.2
Stepper Motor | Skipped Steps / Stall | Available Holding Torque vs. Required Dynamic Torque (0.44 N·m vs. 0.0134 N·m) | 33

The FoS table serves as the final justification for the system architecture. The Chassis FoS of 2.5 validates the use of a 20% PLA infill; even with the hollow internal space required for the acrylic viewing windows, the structural geometry provides more than enough rigidity to survive the maximum holding torque of the NEMA 17 motor in the event the beam is driven continuously into the mechanical hard-stops. The Dynamic Geometry FoS of 2.0 reflects the deliberate application of a safety factor of 2 to the theoretical ball-liftoff threshold, the software-enforced acceleration limit is set to exactly half of the value at which the ball would physically lose contact with the beam, making ball ejection during a K-12 demonstration mathematically impossible. The Stepper Motor FoS of 33 confirms the NEMA 17 is substantially over-capable for the loads imposed by this system, validating the direct-drive architecture. Collectively, these safety factors confirm that the selected concept is a mechanically robust and cost-effective solution for an interactive K-12 educational environment.

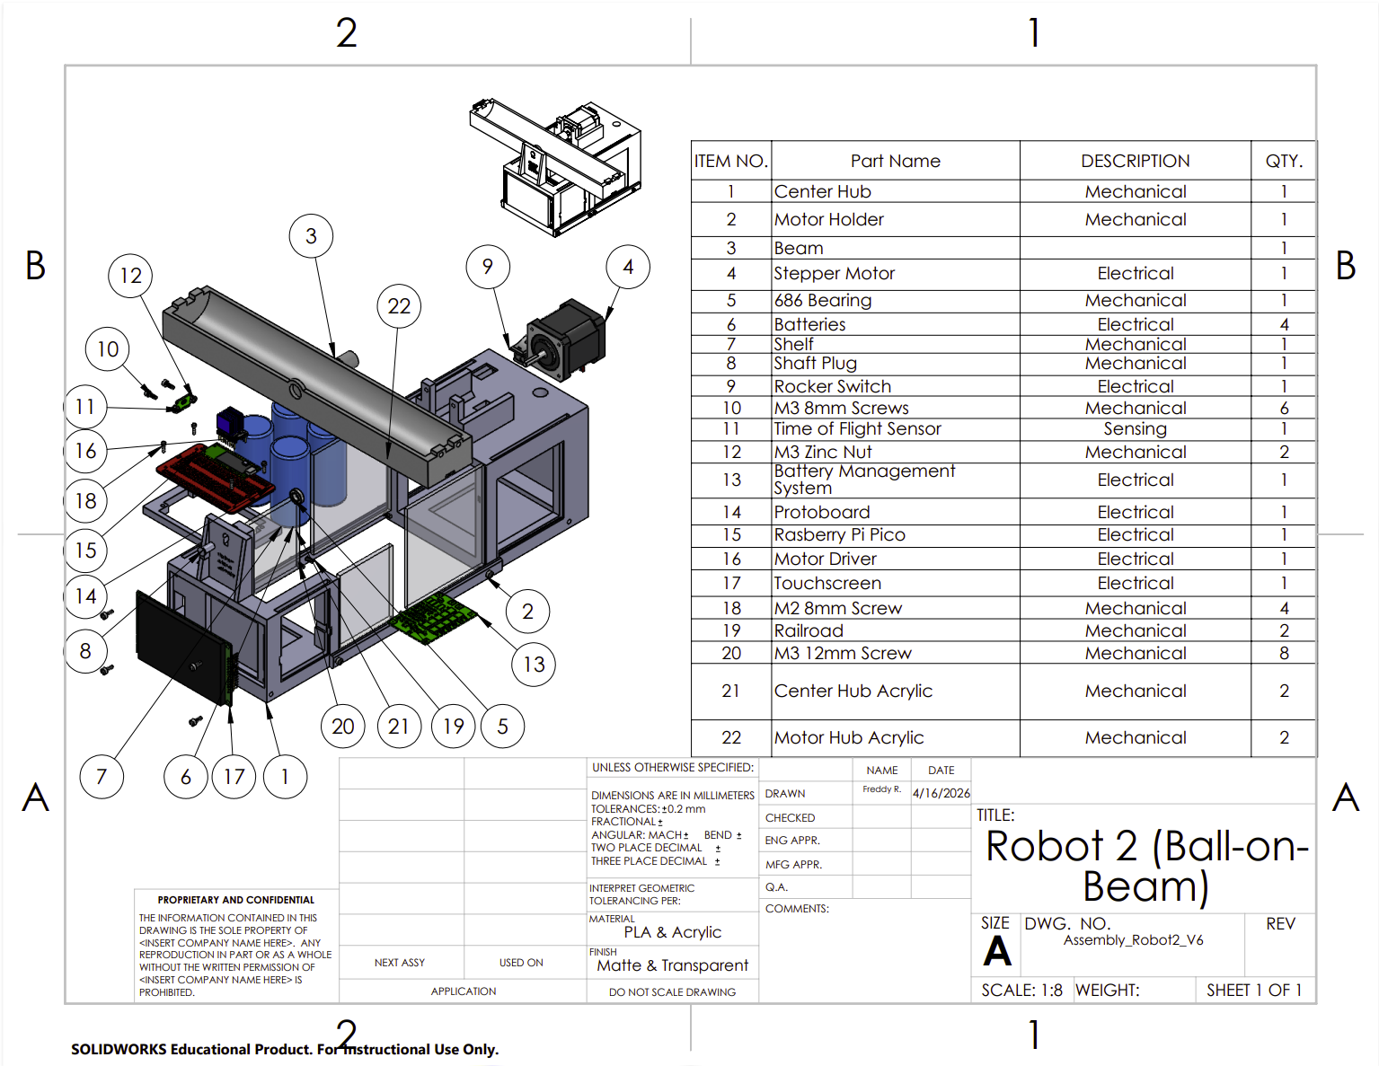
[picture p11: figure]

34 | P a g e

Figure 11. Robot 2 Ball-on-Beam System — SolidWorks Assembly with Sub-System Callouts

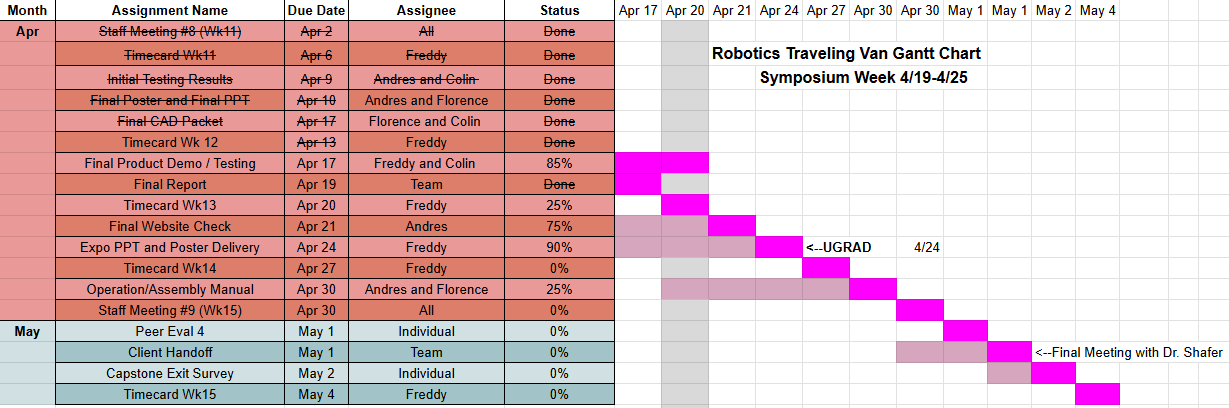
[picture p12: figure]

35 | P a g e

## 7 Schedule and Budget

### 7.1 Schedule

Fig. 12. RTV Gantt Chart Updated 4/19/2026

Tasks remaining are as follows:

- Prepare poster and presentation speeches
- Requires meeting as a team to discuss which sections each individual will take for the presentation and how we want to approach the poster presentation
- Finalize testing and demo procedures
- Requires more testing and fine tuning of the robots and clarifying demo procedures to ensure safe handling
- Create high quality documentation (manual) for both robots
- Will be comprised of all specs sheets and culminating information from building the robots to ensure successful usage and troubleshooting methods.
- Client handoff
- Final meeting with Dr. Shafer to return all unused parts and handoff completed robots with proper manuals
- Final Capstone assignments
- Timesheets, exit surveys, and peer evaluations to conclude the capstone 486C class.

### 7.2 Budget

Given the nature of our project was to create robots that would be built and used by/for NAU outreach events/ambassadors, our budget was very clearly broken up into three main sections. The first was prototyping which included creating a proof of concept, no necessarily a final design, but a working model. The second section was comprised of iteration, our team worked through many issues and problems both mechanically and electrically. Our final designs are very different from our original plan, and this is reflected in our final design section where fine tuning and aesthetics were the core and bulk our budget allocation.

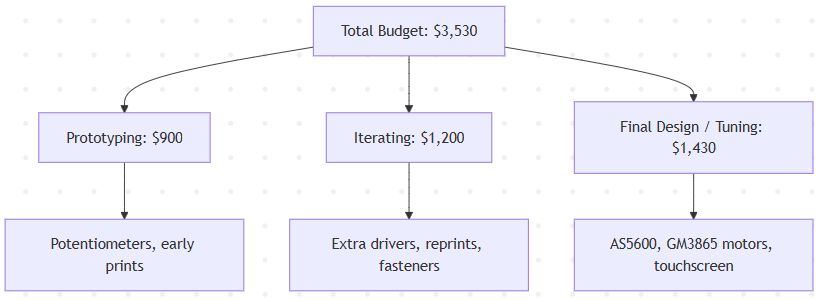
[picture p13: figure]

36 | P a g e

Fig. 13. Diagram of the main three phases of the team budget breakdown

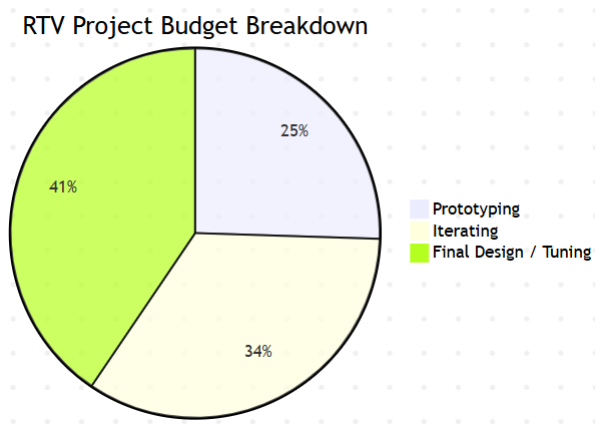
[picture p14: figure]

Fig. 14. Pi Chart of team budget breakdown

### 7.3 Bill of Materials (BoM)

Table 16. Robot 1 General Bill of Materials

37 | P a g e

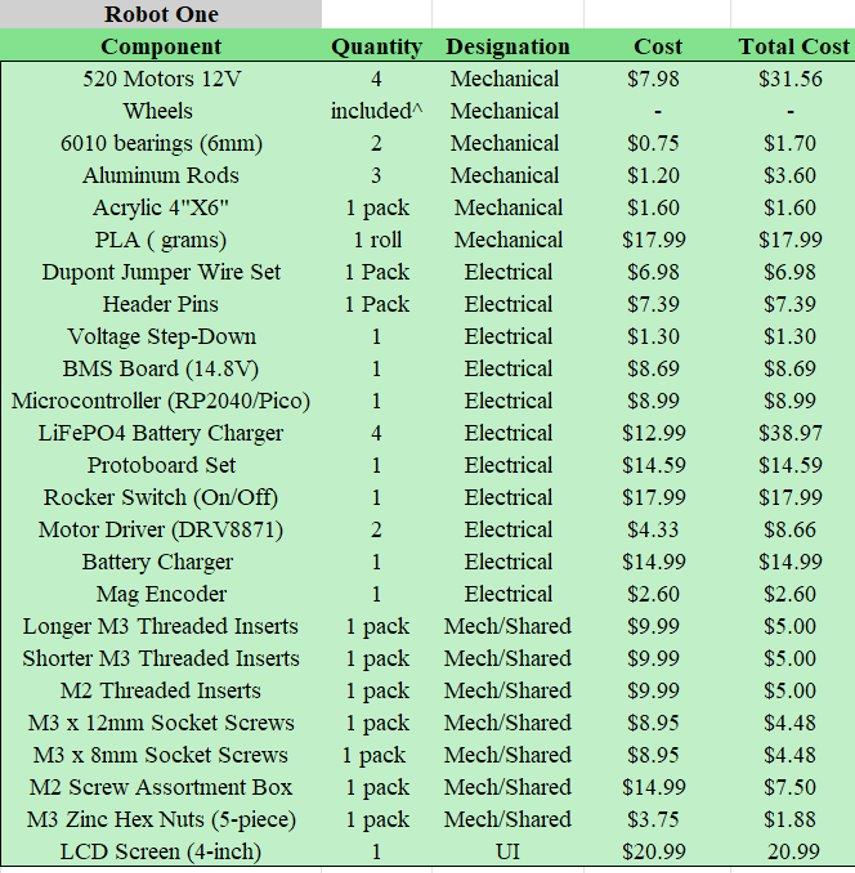
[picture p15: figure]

Total per unit: $246.46

38 | P a g e

Table 17. Robot 1 General Bill of Materials

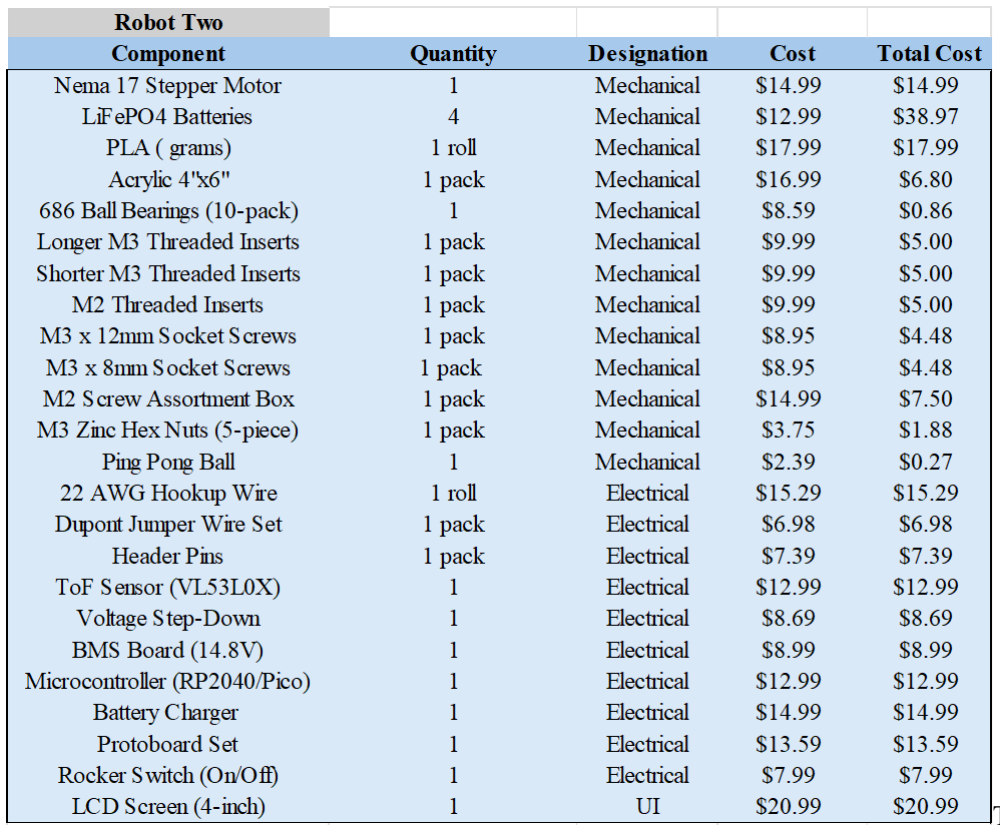
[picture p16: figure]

Total per unit: $242.62

39 | P a g e

## 8 Design Standards

### 8.1 Design Standards Research

Robot 1:

Given that the interface between the metal motors and the 3D-printed chassis holds the primary mechanical risk for Robot #1, we have integrated brass heat-set inserts to maximize joint integrity. Our design is informed by ASME B18.2.8 for clearance hole diameters and ASME B1.13M for metric screw thread profiles, ensuring precise tolerances within our CAD model [6 & 7]. The M3 fastener is our primary hardware standard. We utilize 10mm screws in conjunction with deep-set threaded inserts to distribute high torque loads at the motor mounts. Similarly, we utilize 5mm screws with smaller threaded inserts for low-stress mounting of the logic components and the 4” touchscreen, ensuring a secure fit without compromising the thinner sections of the printed geometry.
In terms of safety and interaction with our target audience, we have identified the pendulum's kinetic energy as a Class 2 Mechanical Source and implemented a dual-layer safeguard. To mitigate risks inherent in a mobile pendulum system, the design implements a "Safety by Separation" strategy derived from IEC 62368-1 [4]. This is achieved by housing the Raspberry Pi Pico and high-current motor circuitry within a four-pillar internal cage, while the 4” touchscreen is mounted externally to a protective bulkhead, isolating the user from "Class 2" electrical and thermal energy sources. Furthermore, mechanical hazards such as pinch points at the pendulum pivot are addressed via a 3D-printed slip-on shroud in accordance with ASTM F963-17 Section 4.18, ensuring the device remains a "fail-to-safe" system during autonomous PID-controlled operation [6].
Additional care was taken to ensure safety and adherence to regulations. FCC Part 15 (Subpart B) regulates "Unintentional Radiators" [5]. Given that the PicoPi uses digital logic switching at high frequencies, this
code ensures that our robot does not emit harmful radio-frequency interference (RFI). Our cage design acts as a basic EMI (Electromagnetic Interference) shield so that we conform to the above-mentioned code. The cage itself, and the chassis for that matter, is made of PLA filament that we run through a 3D printer, RoHS (Restriction of Hazardous Substances) ensures that the 3D printer filament and the lead-free solder used on your PicoPi/circuits do not contain toxic levels of heavy metals (Lead, Cadmium, etc.). We can ensure this is done by tracking materials used in our components. This is crucial for the "Audience-Facing" screen and parts that students may touch.

Table 18. Standard Code for Robot 1

Standard/Code | General Design Affect | Project Application
ASME B1.13M [55] | Thread standardization | Specifies the 60° form for M3 screws and brass inserts to ensure max load transfer
ASME B18.2.8 [56] | Fit and tolerances | Specifies a >1mm close fit clearance to ensure proper insert-screw connection
ASTM F963-17 [57] | Consumer/Toy Safety | Limits gap sizes at the pendulum pivot to under 5mm (via shroud) to prevent finger entrapment
IEC 62368-1 [59] | Energy Source isolation | Validates the 18 mm thick bulkhead wall separating "Class 1" logic from "Class 2" motor power.
FCC Part 15 (sub-sect. B) [60] | RFI Mitigation | Ensures the 133 MHz clock of the PicoPi does not interfere with school infrastructure
RoHS 3 [61] | Material Toxicity | Confirms that all 3D filaments and solder are lead-free (< 1000 ppm) for safe student interaction.

40 | P a g e

### 8.1.1 Robot 1 Annotated Bibliography:

ASME B1.13M: Metric Screw Threads: M Profile. American Society of Mechanical Engineers. This standard specifies the thread profile and standardization for metric threads. For Robot #1, this standard informs the 60° thread form used for the M3 screws and brass heat-set inserts. Adhering to this profile ensures precise tolerances within the CAD model and maximizes torque load transfer, which is critical for maintaining joint integrity at the metal motor interfaces.

ASME B18.2.8: Clearance Holes for Bolts, Screws, and Studs. American Society of Mechanical Engineers. This standard provides the recommended drill sizes and tolerances for clearance holes. In the context of this project, it is utilized to specify a close fit clearance of >1mm. This tolerance ensures a proper and secure connection between the 10mm/5mm screws and the 3D-printed chassis, facilitating high-torque motor mounting as well as the low-stress mounting of logic components without fracturing thin-walled geometries.

ASTM F963-17: Standard Consumer Safety Specification for Toy Safety. ASTM International. A comprehensive safety standard aimed at mitigating mechanical, chemical, and electrical hazards in consumer products intended for youth interaction. Specifically, Section 4.18 is applied to the pendulum system to address pinch point hazards. It dictates the implementation of the 3D-printed slip-on shroud, limiting gap sizes at the pendulum pivot to under 5mm to prevent finger entrapment and ensure the device acts as a "fail-to-safe" system.

FCC Part 15 (Subpart B): Unintentional Radiators. Federal Communications Commission. This federal regulation governs electronic devices that inadvertently emit radio frequency (RF) energy during operation. Because the Raspberry Pi Pico utilizes high-frequency digital logic switching (specifically a 133 MHz clock), this code is applied to ensure the device does not emit harmful radio-frequency interference (RFI) that could disrupt school infrastructure. The 3D-printed PLA cage design serves as a baseline electromagnetic interference (EMI) shield to help meet this requirement.

IEC 62368-1: Audio/video, information and communication technology equipment - Part 1: Safety requirements. International Electrotechnical Commission. This hazard-based safety standard focuses on energy source isolation and safeguards. It directly informs the "Safety by Separation" strategy used in Robot #1. By classifying the high-current motor circuitry and pendulum kinetic energy as a Class 2 source, the standard validates the use of an 18mm thick protective bulkhead wall to isolate these hazards from the Class 1 logic components (the 4” touchscreen), keeping the user safely separated from electrical and thermal risks.

RoHS 3 (Directive 2015/863): Restriction of Hazardous Substances. European Union. This directive restricts the use of specific hazardous materials, such as heavy metals, in electrical and electronic equipment. For this project, it serves as the benchmark for material toxicity, confirming that the PLA filament used for the chassis and cage, as well as the solder for the PicoPi circuits, are lead-free (<1000 ppm). Material tracking ensures that the "Audience-Facing" screens and touchpoints are entirely safe for student interaction.
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

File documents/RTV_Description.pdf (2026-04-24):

Project Description: The Robotics Traveling Van project focuses on designing and building two low-cost, portable educational robots that demonstrate core control system concepts for K-12 outreach. Sponsored by Dr. Michael Shafer at Northern Arizona University, the project aims to create safe, highly durable, and visually engaging platforms that help students connect physical robot kinematics to abstract ideas like feedback loops, stability, and actuation. The team is developing two integrated systems: Robot 1, an inverted pendulum robot designed to maintain dynamic balance while students physically interact with it, and Robot 2, a ball-balancing platform that utilizes a center-pivot ball-on-beam architecture. Both robots are engineered specifically for a pilot-run manufacturing scale, ensuring they are classroom-friendly, robust enough to survive repeated physical demonstrations, and visually professional.
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

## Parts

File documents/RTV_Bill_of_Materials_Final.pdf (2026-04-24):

Pendulu
m
Robot
Item #

Ball-on-Beam
Robot
Item #
Part Name (Material) | Make /
Buy | Vendor & Purchase Link | Pendulum Robot QTY

Ball-on-Beam QTY

Pack Unit /
Est. Weight

Pack Cost /
Mat. Cost*

Cost / Piece
or / Gram*

Total Cost
Pendulum Robot

Total Cost
Ball-on-Beam
1 | — | Frame Base (PLA) | Make | 3D Printed In-House | 1 | — | ~200g (PLA @ $17.99/kg) | $3.60 | $3.598 | $3.60 | $0.00
2 | — | Frame Top (PLA) | Make | 3D Printed In-House | 1 | — | ~160g (PLA @ $17.99/kg) | $2.88 | $2.878 | $2.88 | $0.00
3 | — | Magnetic Potentiometer Mount (PLA) | Make | 3D Printed In-House | 1 | — | ~30g (PLA @ $17.99/kg) | $0.54 | $0.540 | $0.54 | $0.00
4 | — | Yahboom Motor Bracket (PLA) | Make | 3D Printed In-House | 4 | — | ~15g ea (PLA @ $17.99/kg) | $0.27 | $0.270 | $1.08 | $0.00
16 | — | Pendulum Shell (TPU) | Make | 3D Printed In-House (https://us.elegoo.com/products/rapid-tpu-filament-1-75mm-colored-1kg) | 1 | — | ~100g (TPU @ $22.99/kg — est.) | $2.30 | $2.299 | $2.30 | $0.00
7·1 | — | Pendulum Interior Bracket (PLA) | Make | 3D Printed In-House | 1 | — | ~50g (PLA @ $17.99/kg) | $0.90 | $0.900 | $0.90 | $0.00
7·4 | — | Pendulum Shoulder Bracket / Elbow (PLA) | Make | 3D Printed In-House | 2 | — | ~50g ea (PLA @ $17.99/kg) | $0.90 | $0.900 | $1.80 | $0.00
7·5 | — | Pendulum Arm Side Beam (Aluminum 6061, Ø6×82.5mm) | Make | Cut from Aluminum Rod Stock (see Section 2) | 2 | — | 82.5mm × Ø6mm cut | $0.00 | $0.000 | $0.00 | $0.00
7·3 | — | Pendulum Long Interior Segment (Aluminum 6061, Ø4.67×53.3mm) | Make | Cut from Aluminum Rod Stock (see Section 2) | 1 | — | 53.3mm × Ø4.67mm cut | $0.00 | $0.000 | $0.00 | $0.00
7·2 | — | Pendulum Small Inner Segment (Aluminum 6061, Ø4.67×37mm) | Make | Cut from Aluminum Rod Stock (see Section 2) | 1 | — | 37mm × Ø4.67mm cut | $0.00 | $0.000 | $0.00 | $0.00
19 | — | Acrylic Window (Acrylic, 153.4×122×3.13mm) | Make | Cut from Acrylic Sheet (see Section 2) | 1 | — | 153.4×122mm cut | $0.00 | $0.000 | $0.00 | $0.00
— | 1 | Center Hub (PLA) | Make | 3D Printed In-House | — | 1 | ~175g (PLA @ $17.99/kg) | $3.15 | $3.148 | $0.00 | $3.15
— | 2 | Motor Holder (PLA) | Make | 3D Printed In-House | — | 1 | ~140g (PLA @ $17.99/kg) | $2.52 | $2.519 | $0.00 | $2.52
— | 3 | Beam (PLA, 304.8mm) | Make | 3D Printed In-House | — | 1 | ~110g (PLA @ $17.99/kg) | $1.98 | $1.979 | $0.00 | $1.98
— | 7 | Shelf / Protoboard Shelf (PLA) | Make | 3D Printed In-House | — | 1 | ~55g (PLA @ $17.99/kg) | $0.99 | $0.989 | $0.00 | $0.99
— | 8 | Shaft Plug Key (PLA) | Make | 3D Printed In-House | — | 1 | ~15g (PLA @ $17.99/kg) | $0.27 | $0.270 | $0.00 | $0.27
— | 19 | Railroad / Bracket (PLA, 194.15mm) | Make | 3D Printed In-House | — | 2 | ~27.5g ea (PLA @ $17.99/kg) | $0.49 | $0.495 | $0.00 | $0.99
— | 21 | Center Hub Acrylic (Acrylic, 60.96×72.2×4.12mm) | Make | Cut from Acrylic Sheet (see Section 2) | — | 2 | 60.96×72.2mm cut | $0.00 | $0.000 | $0.00 | $0.00
— | 22 | Motor Hub Acrylic (Acrylic, 88.9×99.06×3.4mm) | Make | Cut from Acrylic Sheet (see Section 2) | — | 2 | 88.9×99.06mm cut | $0.00 | $0.000 | $0.00 | $0.00
SECTION 1 — Estimated Print Material Cost (Reference Only — NOT included in grand total below) | | | | | | | | | | $13.09 | $9.89
5, 8 | — | 520 DC Motors w/ Wheels & Brackets (GM3865-520) | Buy | Amazon — Yahboom (https://www.amazon.com/Yahboom-GM3865-520-Encoder-Suitable-Wheelbase/dp/B0F1N9VZSK/) | 4 | — | 4-pack | $31.56 | $7.890 | $31.56 | $0.00
— | 4 | Nema 17 Stepper Motor | Buy | Amazon (https://a.co/d/0iomp5Cd) | — | 1 | 1 (each) | $14.99 | $14.990 | $0.00 | $14.99
10 | — | 606-2RS Deep Groove Bearings (6mm bore) | Buy | Amazon — uxcell (https://www.amazon.com/uxcell-606-2RS-Groove-Bearing-Bearings/dp/B07FF6FSK7/) | 2 | — | 1 (each) | $0.85 | $0.850 | $1.70 | $0.00
— | 5 | 686-2RS Ball Bearings | Buy | Amazon — uxcell (https://www.amazon.com/uxcell-Groove-Bearings-Inner-Chrome/dp/B082PQ45Q9) | — | 1 | 10-pack | $8.59 | $0.859 | $0.00 | $0.86
— | — | Acrylic Sheets 4"×6" (raw stock for Cut parts in Section 1) | Buy | Amazon — KAITELA (https://a.co/d/034rLgLD) | 1 | 1 | ~10-sheet pack | $16.99 | $1.699 | $1.70 | $1.70
7·5–7·2 | — | Aluminum 6061 Round Rod (1/4"×13", raw stock for Pendulum Arm sub-parts) | Buy | Amazon (https://www.amazon.com/Pieces-Aluminum-Round-Extruded-Diameter/dp/B0BB39RHVD) | 3 | — | 10-pack | $11.99 | $1.199 | $3.60 | $0.00
6 | 6 | LiFePO4 Batteries (3.2V 32700) | Buy | Amazon — CITYORK (https://a.co/d/05Zu4MYw) | 4 | 4 | 4-pack | $38.97 | $9.743 | $38.97 | $38.97
9 | — | Longer M3 Threaded Inserts (M3×5.7) — R1: 19 pcs | R2: 12 pcs | Buy | Amazon — Ruthex (https://www.amazon.com/ruthex-M3-Threaded-Inserts-RX-M3x5-7/dp/B08BCRZZS3/) | 19 | 12 | 50-pack | $9.99 | $0.200 | $3.80 | $2.40
12 | — | Shorter M3 Threaded Inserts (M3×4.0) — R1: 12 pcs | R2: 2 pcs | Buy | Amazon — Ruthex (https://www.amazon.com/Threaded-Inserts-Plastic-3mm-10mm-Pringting/dp/B0FD88XTV4/) | 12 | 2 | 50-pack | $9.99 | $0.200 | $2.40 | $0.40
— | — | M2 Threaded Inserts — R2: 4 pcs | Buy | Amazon — Ruthex (https://www.amazon.com/ruthex-Threaded-Insert-Pieces-Ultrasound/dp/B088QJDPKK) | — | 4 | 50-pack | $9.99 | $0.200 | $0.00 | $0.80
15 | 10 | M3 × 8mm Socket Head Cap Screws — R1: 47 pcs | R2 item #10: 6 pcs | Buy | Digital Machinery Inc. (https://www.digmach.com/products/m3-socket-head-cap-screws?variant=44391439564982) | 47 | 6 | 100-pack | $8.95 | $0.090 | $4.21 | $0.54
— | 20 | M3 × 12mm Socket Head Cap Screws — R2 item #20: 8 pcs | Buy | Digital Machinery Inc. (https://www.digmach.com/products/m3-socket-head-cap-screws?variant=44395524063414) | — | 8 | 100-pack | $8.95 | $0.090 | $0.00 | $0.72
— | 18 | M2 Screw Assortment — R2 item #18: 4×M2×8mm pcs | Buy | Amazon (https://www.amazon.com/dp/B0FGV5K8BT) | — | 4 | 200-pc asst. | $14.99 | $0.075 | $0.00 | $0.30
— | 12 | M3 Zinc Hex Nuts — R2 item #12: 2 pcs | Buy | Home Depot — Everbilt (https://www.homedepot.com/p/Everbilt-M3-0-5-Zinc-Hex-Nut-5-Pieces-862798/323368368) | — | 2 | 5-pack | $3.75 | $0.750 | $0.00 | $1.50
— | 16 | Stepper Motor Driver (TMC2208) | Buy | Amazon — TMC2208 (https://www.amazon.com/Printer-Stepper-Stepstick-Screwdriver-Controller/dp/B08DFVD4LL) | — | 1 | 1 (each) | $17.99 | $17.990 | $0.00 | $17.99
19 | — | Motor Driver (DRV8871) — Pendulum Robot only | Buy | Amazon / DigiKey (https://a.co/d/4KhO1o4) | 2 | — | 1 (each) | $4.33 | $4.330 | $8.66 | $0.00
11 | — | AS5600 Magnetic Encoder — Pendulum Robot only | Buy | Amazon — UMLIFE (https://www.amazon.com/Magnetic-Encoder-Induction-Measurement-Precision/dp/B094F8H591) | 1 | — | 1 (each) | $2.60 | $2.600 | $2.60 | $0.00
— | 11 | ToF Distance Sensor (VL53L0X) — Ball-on-Beam only | Buy | Amazon — Qoroos (https://www.amazon.com/Qoroos-VL53L0X-Breakout-Interface-Communication/dp/B0F1MRW55R/) | — | 1 | 1 (each) | $12.99 | $12.990 | $0.00 | $12.99
— | — | Voltage Step-Down / Buck Converter | Buy | Amazon — Euogeudel (https://a.co/d/0fSkhqZt) | 1 | 1 | 1 (each) | $8.69 | $8.690 | $8.69 | $8.69
17 | 13 | BMS Board (4S 30A, 14.8V) | Buy | Amazon (https://a.co/d/0a1V8Mcg) | 1 | 1 | 1 (each) | $8.99 | $8.990 | $8.99 | $8.99
18 | 15 | Microcontroller (RP2040 / Pi Pico) | Buy | Amazon / Adafruit (https://a.co/d/00L1Mz8x) | 1 | 1 | 1 (each) | $12.99 | $12.990 | $12.99 | $12.99
— | — | LiFePO4 Battery Charger (14.6V) | Buy | Amazon (https://a.co/d/09YwCauu) | 1 | 1 | 1 (each) | $14.59 | $14.590 | $14.59 | $14.59
— | 14 | Protoboard / Solderable Breadboard | Buy | Amazon — EPLZON (https://www.amazon.com/EPLZON-Solder-able-Breadboard-Electronics-Compatible/dp/B09X1DMSYZ/) | 1 | 1 | 1 (each) | $14.59 | $14.590 | $14.59 | $14.59
14 | 9 | Rocker Switch (On/Off) | Buy | Amazon — DaierTek KCD1 (https://www.amazon.com/DaierTek-250VAC-Rocker-KCD1-101-Plastic/dp/B07S2QJKTX/) | 1 | 1 | 1 (each) | $7.99 | $7.990 | $7.99 | $7.99
— | — | Dupont Jumper Wire Set (120-piece) | Buy | Amazon — Elegoo (https://www.amazon.com/Elegoo-EL-CP-004-Multicolored-Breadboard-arduino/dp/B01EV70C78/) | 1 | 1 | 120-pc set | $6.98 | $6.980 | $6.98 | $6.98
— | — | Header Pins (40-pin strip) | Buy | Amazon — Honbay (https://www.amazon.com/dp/B06Y4S6G29) | 1 | 1 | 40-pc strip | $7.39 | $7.390 | $7.39 | $7.39
— | — | DIP Socket Kit — Pendulum Robot only | Buy | Amazon — CHIPNEW (https://a.co/d/fLwAAwo) | 1 | — | 1 (kit) | $9.99 | $9.990 | $9.99 | $0.00
— | — | 22 AWG Hookup Wire — Ball-on-Beam only | Buy | Amazon — TUOFENG (https://www.amazon.com/TUOFENG-Hookup-Wires-6-Different-Colored/dp/B07TX6BX47/) | — | 1 | 1 roll | $15.29 | $15.290 | $0.00 | $15.29
13 | 17 | LCD Capacitive Touchscreen (4-inch, 320×480) | Buy | Amazon — Hosyond (https://a.co/d/0eAP9Pdl) | 1 | 1 | 1 (each) | $20.99 | $20.990 | $20.99 | $20.99
— | — | PLA Filament (R1: ~600g used | R2: ~550g used | 1 roll covers each robot with surplus) | Buy | R1: Amazon — Overture | R2: Creality Hyper PLA (https://store.creality.com/products/hyper-series-pla-3d-printing-filament-1kg) | 1 | 1 | 1 kg roll (1,000g) | $17.99 | $17.990 | $10.79 | $9.00
— | — | TPU Filament (R1: ~100g used — Pendulum Shell only | est. price — verify on Elegoo store) | Buy | Elegoo — Rapid TPU Filament 1.75mm (https://us.elegoo.com/products/rapid-tpu-filament-1-75mm-colored-1kg) | 1 | — | 1 kg roll (1,000g) | $22.99 | $22.990 | $2.30 | $0.00
$246.46 | $242.62

## BILL OF MATERIALS — Robotics Traveling Van (RTV) Capstone Project

Project: Robotics Traveling Van (RTV) | Two-Robot Assembly | Spring 2026 | Drawn By: Freddy Rivera · Florence Fasugbe · Colin Parsinia · Andres Gonzales | April 2026

HOW TO READ THIS BOM: Column A = Item # cross-referencing balloon numbers in the Pendulum Robot CAD drawing (RTV_Robot_1_Final_CAD_Assembly). Column B = Item # cross-referencing balloon numbers in the Ball-on-Beam Robot CAD drawing (RTV_Robot_2_Final_CAD_Assembly). A dash (—) means the part is not used in that robot. Parts with quantities in both columns are shared components. Section 1 shows estimated print material costs for reference — these are NOT included in the grand total.

SECTION 1 — Custom 3D Printed & Fabricated Parts (Make) | * Columns I–L show estimated print material cost (grams × $/g) for reference only — NOT included in grand total
↳ RTV Pendulum Robot — 3D Printed Parts | Ref: RTV_Robot_1_Final_CAD_Assembly
↳ Pendulum Arm Sub-Assembly — R1 Item #7 | Ref: RTV_Pendulum_Arm_Final_Sub_Assembly
↳ RTV Ball-on-Beam Robot — 3D Printed Parts | Ref: RTV_Robot_2_Final_CAD_Assembly

SECTION 2 — Mechanical & Structural Components (Buy)

SECTION 3 — Fasteners & Hardware (Buy)

SECTION 4 — Electrical & Electronics (Buy)

SECTION 5 — UI Components (Buy)

SECTION 6 — Bulk Materials (Reference Only — Do Not Include in Per-Unit Cost Total) | PLA: $17.99/kg · TPU: $22.99/kg (est. — verify on Elegoo store)
GRAND TOTAL — PURCHASED COST PER UNIT (Sections 2–5 only | Section 1 print material costs shown separately above)

* Column headers 'Pack Cost / Mat. Cost' and 'Cost/Piece or /Gram' serve dual purpose: for Buy rows they show purchasing data; for Make rows (Section 1) they show print material cost data.

LEGEND & NOTES

Make (Section 1): Parts designed and produced in-house by the team. Columns I–L show estimated filament material cost calculated as: grams used × (filament price ÷ 1,000g). This cost is NOT included in the grand total — it is shown for transparency. Aluminum and acrylic cut parts show $0.00 here because their raw material cost is already captured in Section 2.

Buy (Sections 2–5): Parts purchased from an external vendor. Cost Per Piece = Pack Cost ÷ Pack Size. Total = Cost Per Piece × Quantity per robot.

Section 6 — Bulk Materials: PLA and TPU filament are listed for procurement reference only. R1 uses ~600g PLA + ~100g TPU. R2 uses ~550g PLA. One 1kg roll covers each robot with surplus. TPU pack cost is an estimate — verify current price at the Elegoo store link.

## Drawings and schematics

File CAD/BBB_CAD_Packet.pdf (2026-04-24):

3
9 | 4

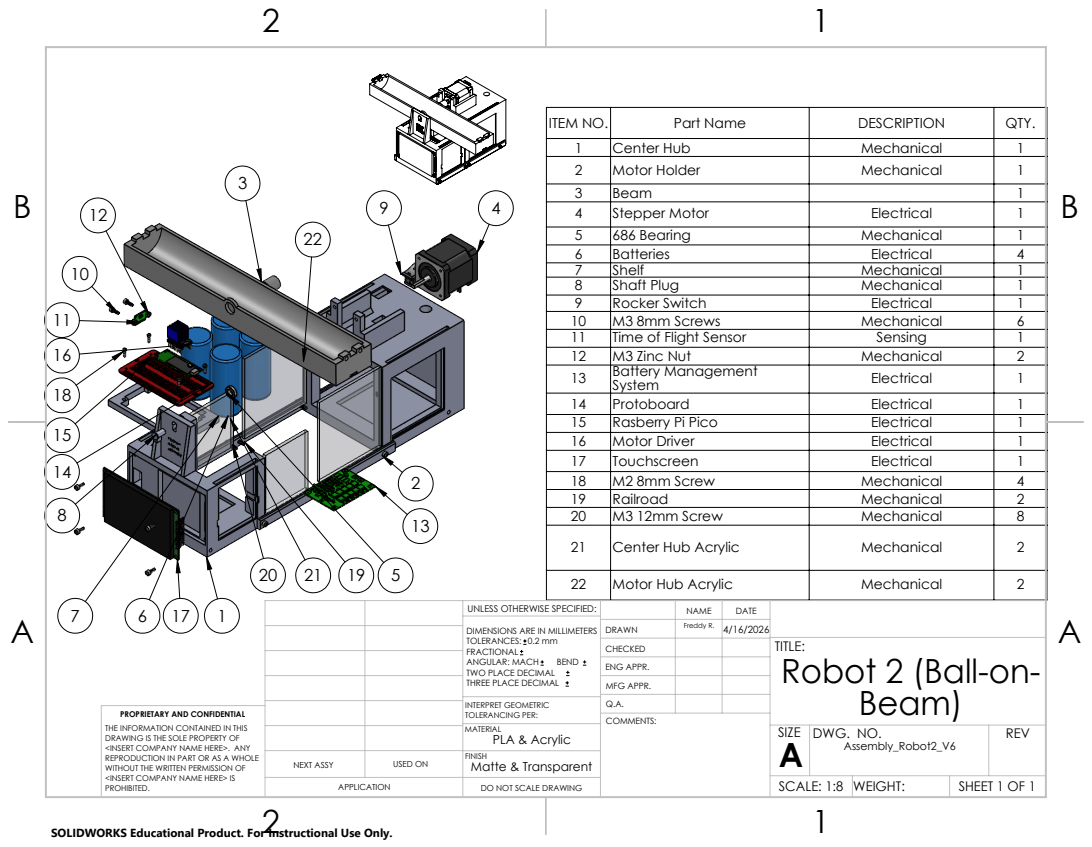
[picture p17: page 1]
COMMENTS:

ITEM NO. | Part Name | DESCRIPTION | QTY.
1 | Center Hub | Mechanical | 1
2 | Motor Holder | Mechanical | 1
3 | Beam | | 1
4 | Stepper Motor | Electrical | 1
5 | 686 Bearing | Mechanical | 1
6 | Batteries | Electrical | 4
7 | Shelf | Mechanical | 1
8 | Shaft Plug | Mechanical | 1
9 | Rocker Switch | Electrical | 1
10 | M3 8mm Screws | Mechanical | 6
11 | Time of Flight Sensor | Sensing | 1
12 | M3 Zinc Nut | Mechanical | 2
13 | Battery Management System | Electrical | 1
14 | Protoboard | Electrical | 1
15 | Rasberry Pi Pico | Electrical | 1
16 | Motor Driver | Electrical | 1
17 | Touchscreen | Electrical | 1
18 | M2 8mm Screw | Mechanical | 4
19 | Railroad | Mechanical | 2
20 | M3 12mm Screw | Mechanical | 8
21 | Center Hub Acrylic | Mechanical | 2

22 | Motor Hub Acrylic | Mechanical | 2
CHECKED | | | TITLE: Robot 2 (Ball-on- Beam)

UNLESS OTHERWISE SPECIFIED: | | NAME | DATE
DIMENSIONS ARE IN MILLIMETERS TOLERANCES: 0.2 mm FRACTIONAL ANGULAR: MACH BEND TWO PLACE DECIMAL THREE PLACE DECIMAL | DRAWN | | 4/16/2026 Freddy R.

ENG APPR.
MFG APPR.

INTERPRET GEOMETRIC TOLERANCING PER: | Q.A.
MATERIAL PLA & Acrylic | | SIZE A | DWG. NO. Assembly_Robot2_V6 | REV

PROPRIETARY AND CONFIDENTIAL
THE INFORMATION CONTAINED IN THIS
DRAWING IS THE SOLE PROPERTY OF
<INSERT COMPANY NAME HERE>. ANY
REPRODUCTION IN PART OR AS A WHOLE
WITHOUT THE WRITTEN PERMISSION OF
<INSERT COMPANY NAME HERE> IS
PROHIBITED.

NEXT ASSY | USED ON | FINISH Matte & Transparent

APPLICATION | DO NOT SCALE DRAWING | | SCALE: 1:8 | WEIGHT: | SHEET 1 OF 1

SOLIDWORKS Educational Product. For Instructional Use Only.

88.90
3.40

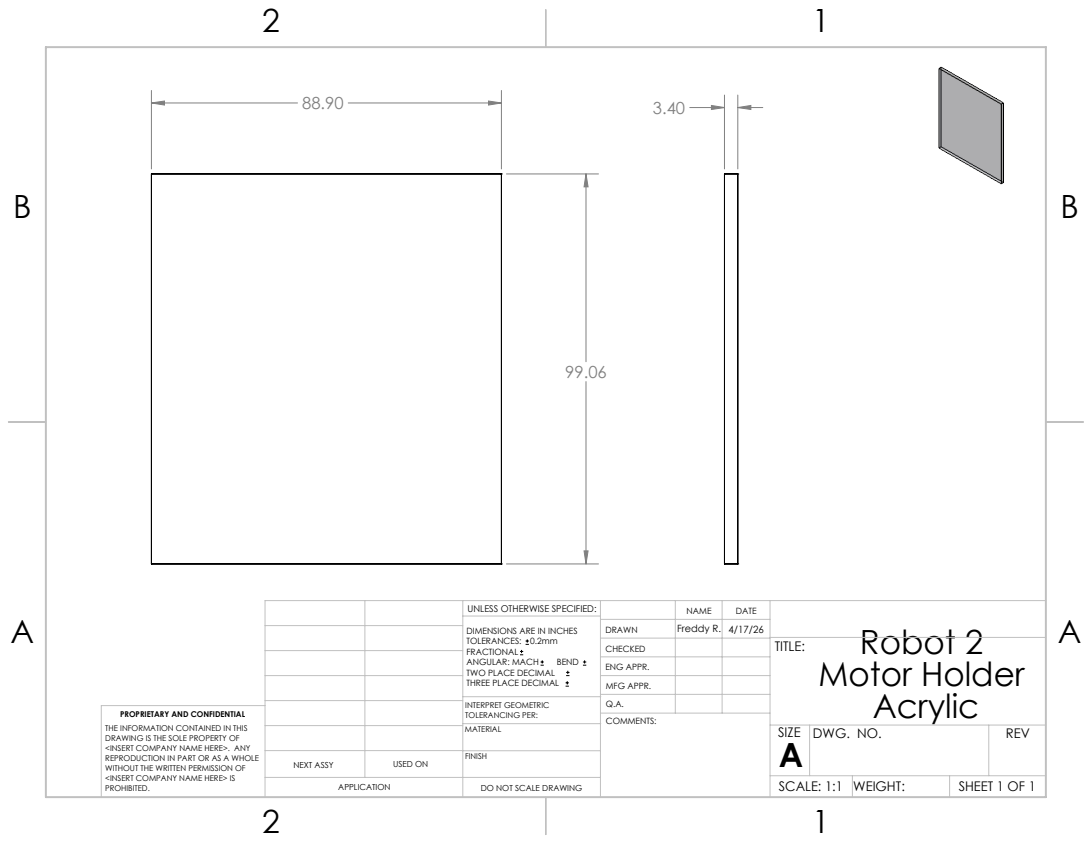
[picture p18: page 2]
COMMENTS:

UNLESS OTHERWISE SPECIFIED: | | NAME | DATE | Robot 2
DIMENSIONS ARE IN INCHES TOLERANCES: 0.2mm FRACTIONAL ANGULAR: MACH BEND TWO PLACE DECIMAL THREE PLACE DECIMAL | DRAWN | Freddy R. | 4/17/26

CHECKED | | | TITLE: Motor Holder Acrylic

ENG APPR.
MFG APPR.

INTERPRET GEOMETRIC TOLERANCING PER: | Q.A.
MATERIAL | | SIZE A | DWG. NO. | REV

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

NEXT ASSY | USED ON | FINISH

DO NOT SCALE DRAWING | | SCALE: 1:1 | WEIGHT: | SHEET 1 OF 1

60.96
4.12

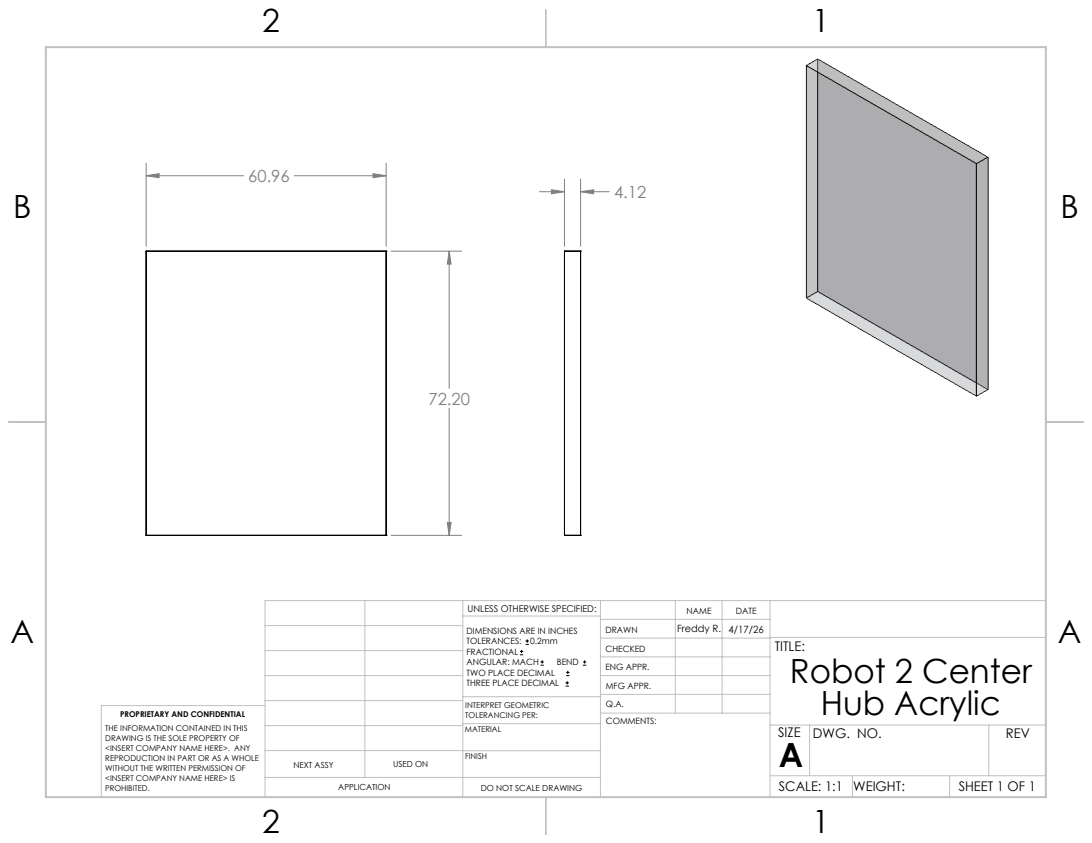
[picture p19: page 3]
COMMENTS:

UNLESS OTHERWISE SPECIFIED: | | NAME | DATE
DIMENSIONS ARE IN INCHES TOLERANCES: 0.2mm FRACTIONAL ANGULAR: MACH BEND TWO PLACE DECIMAL THREE PLACE DECIMAL | DRAWN | Freddy R. | 4/17/26

CHECKED | | | TITLE: Robot 2 Center Hub Acrylic

ENG APPR.
MFG APPR.

INTERPRET GEOMETRIC TOLERANCING PER: | Q.A.
MATERIAL | | SIZE A | DWG. NO. | REV

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

NEXT ASSY | USED ON | FINISH

DO NOT SCALE DRAWING | | SCALE: 1:1 | WEIGHT: | SHEET 1 OF 1

28.18

5.59

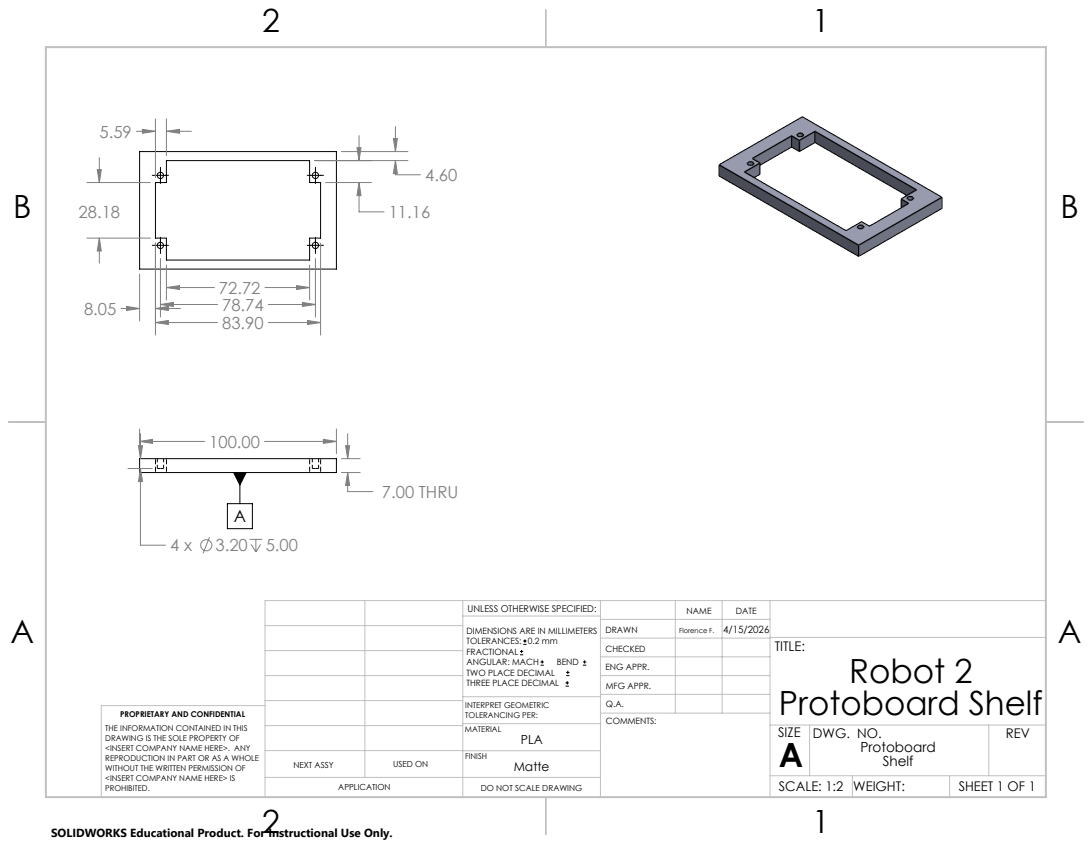
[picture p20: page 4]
7.00 THRU; COMMENTS:

UNLESS OTHERWISE SPECIFIED: | | NAME | DATE

DIMENSIONS ARE IN MILLIMETERS TOLERANCES: 0.2 mm FRACTIONAL ANGULAR: MACH BEND TWO PLACE DECIMAL THREE PLACE DECIMAL | DRAWN | Florence F. | 4/15/2026

CHECKED | | | TITLE: Robot 2 Protoboard Shelf

ENG APPR.
MFG APPR.

INTERPRET GEOMETRIC TOLERANCING PER: | Q.A.
MATERIAL PLA | | SIZE A | DWG. NO. Protoboard Shelf | REV

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

NEXT ASSY | USED ON | Matte FINISH

SCALE: 1:2 | WEIGHT:

6.00

5.49

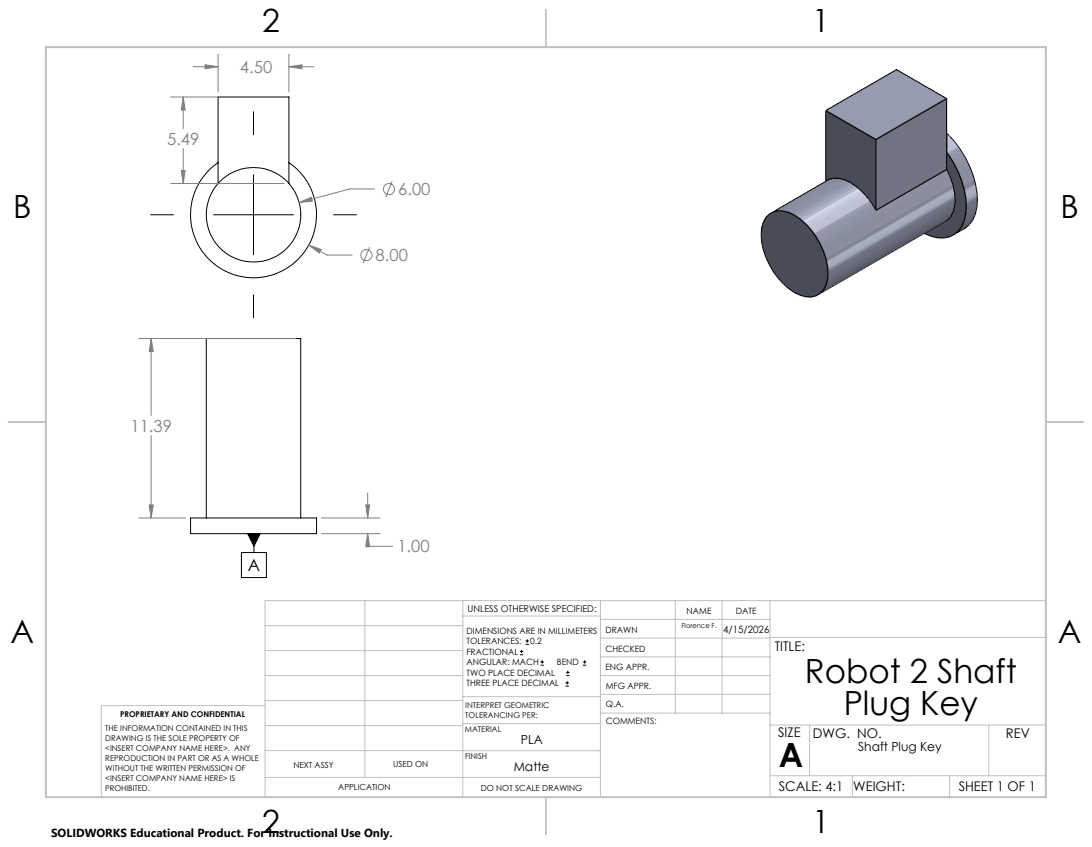
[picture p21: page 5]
COMMENTS:

UNLESS OTHERWISE SPECIFIED: | | NAME | DATE

DIMENSIONS ARE IN MILLIMETERS TOLERANCES: 0.2 FRACTIONAL ANGULAR: MACH BEND TWO PLACE DECIMAL THREE PLACE DECIMAL | DRAWN | | 4/15/2026 Florence F.

CHECKED | | | TITLE: Robot 2 Shaft Plug Key

ENG APPR.
MFG APPR.

INTERPRET GEOMETRIC TOLERANCING PER: | Q.A.
MATERIAL PLA | | SIZE A | DWG. NO. Shaft Plug Key | REV

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

NEXT ASSY | USED ON | Matte FINISH

SCALE: 4:1 | WEIGHT:

9.70

2.12

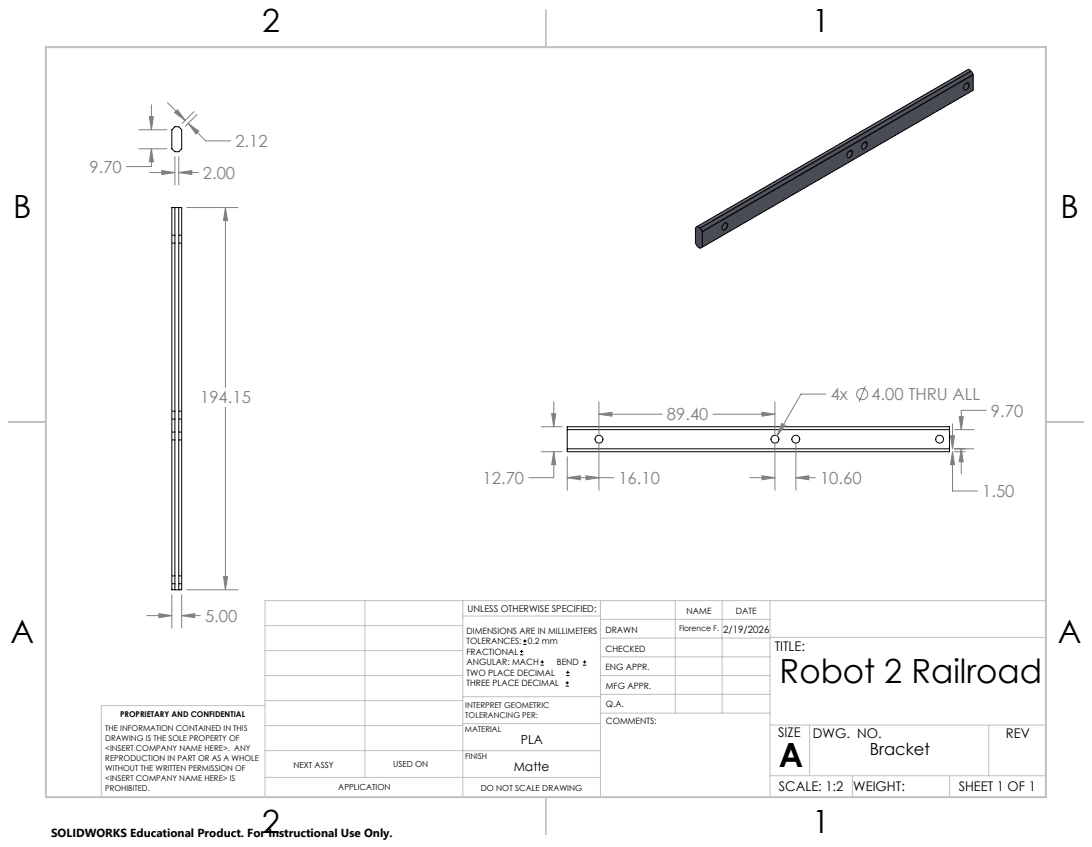
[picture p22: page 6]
4x 4.00 THRU ALL; COMMENTS:

UNLESS OTHERWISE SPECIFIED: | | NAME | DATE
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

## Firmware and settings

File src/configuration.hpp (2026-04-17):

#ifndef CONFIGURATION_HPP
#define CONFIGURATION_HPP

// ToF sensor
#define I2C_PORT i2c0
#define SDA_PIN 4
#define SCL_PIN 5

#define TOUCH_I2C_PORT 1 // set to 0 for I2C0, or 1 for I2C1

// touch screen pins I2C1
// NOTE: the ToF and the touchscreen can't share the same I2C bus, one must use
// I2C0 and the other I2C1
#define TOUCH_SDA 2
#define TOUCH_SCL 3
#define TOUCH_RST 6
#define TOUCH_INT 7

#define MOTOR_STEP_PIN 16
#define MOTOR_DIR_PIN 17
#define STEP_ANGLE 1.80f

// microstepping logic (TMC2208 MS1=H, MS2=H)
// 360 / 1.8 = 200 full steps. 200 * 16 = 3200 microsteps/rev.
// #define MICROSTEPS 16
#define STEPS_PER_REV 1800

// #define MOTOR_STEP_INTERVAL_US 400

#define PID_SAMPLE_MS 20 // matches VL53L0X timing

#define DEFAULT_KP 0.75f
#define DEFAULT_KI 0.30f
#define DEFAULT_KD 0.05f

#define PID_LIMIT_MIN -5.0f
#define PID_LIMIT_MAX 5.0f

#define BALL_SETPOINT_CM 16.5f
#define BALL_MIN_DIST_CM 3.0f
#define BALL_MAX_DIST_CM 27.0f
#define BALL_ABSENT_DIST_CM 28.5f
#define BALL_RESUME_MIN_CM 13.0f
#define BALL_RESUME_MAX_CM 19.0f
#define FT6336U_ADDR 0x38

enum MOTOR_DIRECTION { COUNTER_CLOCKWISE = 1, CLOCKWISE = 0 };

#endif // CONFIGURATION_HPP

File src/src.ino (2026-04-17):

#include <Arduino.h>
#include "hardware/gpio.h"
#include "hardware/i2c.h"
#include "hardware/pwm.h"
#include "pico/multicore.h"
#include <math.h>

#include "VL53L0X.h"
#include "configuration.hpp"
#include "pid.h"
#include "motor.hpp"
#include "screen.hpp"
#include "touch.hpp"

// shared volatile variables to communicate between loops
volatile float current_distance = 0.0f;
volatile float current_speed = 0.0f;
volatile float current_setpoint = BALL_SETPOINT_CM;
volatile bool system_running = true;

bool hardware_present = true;

// globals for core 1
float distance_val = BALL_SETPOINT_CM;
float set_point = BALL_SETPOINT_CM;
float control_output = 0.0f;

// define our system states
enum SystemState {
  STATE_BALANCING,
  STATE_NEEDS_RESET,
  STATE_WAITING
};

SystemState current_state = STATE_BALANCING;

PID* myPID;
VL53L0X* sensor;
MOTOR* motor;

// ==============================================================================
// CORE 0: TOUCHSCREEN UI
// ==============================================================================
void setup() {
  Serial.begin(115200);
  pinMode(LED_BUILTIN, OUTPUT);
  
  initScreen();
  initTouch(); 
}

void loop() {
  uint32_t loopStart = millis();
  
  // State tracker for our button lockout
  static bool was_touched = false; 

  uint16_t rawX, rawY;
  bool is_touching = readTouch(rawX, rawY);
  
  if (is_touching) {
    // Only fire the button logic if this is a NEW touch event
    if (!was_touched) {
      was_touched = true; // Lockout engaged until finger is lifted
      
      uint16_t mappedX = rawY; 
      uint16_t mappedY = 320 - rawX;

      Serial.printf("Raw -> X: %d, Y: %d | Mapped -> X: %d, Y: %d\r\n", rawX, rawY, mappedX, mappedY);
      
      ButtonID btn = checkButtons(mappedX, mappedY);
      
      switch(btn) {
        case BTN_TOGGLE_BALANCE:
          system_running = !system_running;
          Serial.println(system_running ? "System ON" : "System OFF");
          break;
          
        case BTN_RESET:
          multicore_fifo_push_blocking(0x04); 
          Serial.println("Force Reset Triggered by Core 0");
          break;
          
        case BTN_SETPOINT_UP:
          current_setpoint += 1.0f;
          if (current_setpoint > 25.0f) current_setpoint = 25.0f; 
          break;
          
        case BTN_SETPOINT_DOWN:
          current_setpoint -= 1.0f;
          if (current_setpoint < 5.0f) current_setpoint = 5.0f;   
          break;
          
        case BTN_NONE:
        default:
          break;
      }
    }
  } else {
    // Finger was lifted, unlock the buttons
    was_touched = false;
  }

  updateScreen(current_distance, current_speed, analogReadTemp(), rp2040.getFreeHeap(), 
               millis() - loopStart, current_setpoint, system_running);

  delay(50); 
}

// ==============================================================================
// CORE 1: BALL BALANCING & MOTOR CONTROL
// ==============================================================================
void setup1() {
  delay(2000); 

  // FLUSH THE FIFO: Clear out any garbage from soft-reboots!
  while (multicore_fifo_rvalid()) multicore_fifo_pop_blocking();

  // TOF sensor hardware init
  i2c_init(I2C_PORT, 400 * 1000);
  gpio_set_function(SDA_PIN, GPIO_FUNC_I2C);
  gpio_set_function(SCL_PIN, GPIO_FUNC_I2C);
  gpio_pull_up(SDA_PIN);
  gpio_pull_up(SCL_PIN);

  sensor = new VL53L0X(I2C_PORT, 0x29);
  
  if (!sensor->init()) {
    Serial.println("WARNING: VL53L0X missing! Entering UI Simulation Mode...");
    hardware_present = false; 
  } else {
    Serial.println("Hardware detected. Normal mode active.");
    sensor->setMeasurementTimingBudget(20000);
    sensor->startContinuous(50);
  }

  // PID setup
  myPID = new PID(&distance_val, &control_output, &set_point, 
                  DEFAULT_KP, DEFAULT_KI, DEFAULT_KD, DIRECT);
  myPID->SetMode(AUTOMATIC);
  myPID->SetOutputLimits(PID_LIMIT_MIN, PID_LIMIT_MAX);
  myPID->SetSampleTime(PID_SAMPLE_MS);

  // motor setup
  gpio_init(MOTOR_STEP_PIN);
  gpio_set_dir(MOTOR_STEP_PIN, GPIO_OUT);
  gpio_init(MOTOR_DIR_PIN);
  gpio_set_dir(MOTOR_DIR_PIN, GPIO_OUT);

  motor = new MOTOR(MOTOR_STEP_PIN, MOTOR_DIR_PIN);
  
  if (hardware_present) {
    motor->reset_beam_angle();
  }
}

void loop1() {
  set_point = current_setpoint;

  // 1. DRAIN THE FIFO (Prevents Core 0 freeze & handles UI commands)
  while (multicore_fifo_rvalid()) {
    uint32_t cmd = multicore_fifo_pop_blocking();
    
    if (cmd == 0x01) { 
      // ONLY block for a second value if one actually exists!
      if (multicore_fifo_rvalid()) {
        uint32_t raw_val = multicore_fifo_pop_blocking();
        float new_kp = (float)raw_val / 100.0f;
        myPID->SetTunings(new_kp, myPID->GetKi(), myPID->GetKd());
      } else {
        Serial.println("ERR: Received 0x01 but missing payload!");
      }
    } 
    else if (cmd == 0x04) {
      current_state = STATE_NEEDS_RESET;
      Serial.println("Core 1: Executing Hardware Reset...");
    }
    else if (!hardware_present) {
       Serial.printf("Sim Mode: Ignored Command 0x%02X\r\n", cmd);
    }
  }

  // ui simulation mode
  if (!hardware_present) {
    distance_val = 15.5f + (sin(millis() / 1000.0f) * 8.0f);
    control_output = cos(millis() / 1000.0f) * 50.0f; 

    current_distance = distance_val;
    current_speed = control_output;

    delay(50);
    return; 
  }

  // normal hardware mode
  static float history[3] = {0.0f, 0.0f, 0.0f};
  static uint8_t h_idx = 0;
  static bool first_read = true;
  static float smoothed_angle = 0.0f; // --- NEW: Added for sliding gradient ---

  uint16_t mm = sensor->readRangeContinuousMillimeters();
  
  // 2. SENSOR CHECK
  if (!sensor->timeoutOccurred() && mm < 1200) {
    float raw_distance = (float)mm / 10.0f; 

    if (first_read) {
      history[0] = history[1] = history[2] = raw_distance;
      first_read = false;
    } else {
      history[h_idx] = raw_distance;
      h_idx = (h_idx + 1) % 3; 
    }
    distance_val = (history[0] + history[1] + history[2]) / 3.0f;
  } else {
    // If sensor loses ball, force a fault distance
    distance_val = BALL_ABSENT_DIST_CM; 
  }
    
  bool ball_absent = (distance_val >= BALL_ABSENT_DIST_CM);
  bool ball_stuck = (distance_val <= BALL_MIN_DIST_CM || distance_val >= BALL_MAX_DIST_CM);

  // 3. THE STATE MACHINE
  if (!system_running && current_state != STATE_NEEDS_RESET) {
    myPID->SetMode(MANUAL);
    control_output = 0.0f;
    smoothed_angle = 0.0f;   // --- NEW: Reset smoothing variable ---
    motor->set_angle(0.0f); 
    current_state = STATE_BALANCING; 
  } 
  else {
    switch (current_state) {
      case STATE_BALANCING:
        if (ball_absent || ball_stuck) {
          Serial.printf("ERR: Ball fault (%.1f cm). Initiating reset...\r\n", distance_val);
          current_state = STATE_NEEDS_RESET;
        } else if (system_running) {
          myPID->Compute();

          // --- NEW: ADAPTIVE SMOOTHING GRADIENT ---
          // 1. How far is the ball from the target?
          float error = abs(set_point - distance_val);

          // 2. Define the bounds of our sliding gradient
          float max_error = 15.0f; // Distance (cm) where max smoothing kicks in
          float min_alpha = 0.10f; // Heavy smoothing for the edges (10% new, 90% old)
          float max_alpha = 1.00f; // No smoothing for the center (100% new)

          // 3. Calculate alpha (closer to center = closer to 1.0)
          float alpha = max_alpha - ((error / max_error) * (max_alpha - min_alpha));
          
          // Clamp alpha just in case the ball flies out of bounds
          if (alpha < min_alpha) alpha = min_alpha;
          if (alpha > max_alpha) alpha = max_alpha;

          // 4. Apply the Exponential Moving Average filter
          smoothed_angle = (alpha * control_output) + ((1.0f - alpha) * smoothed_angle);

          // Send the smoothed angle to the motor
          motor->set_angle(smoothed_angle);
          // ----------------------------------------
        }
        break;

      case STATE_NEEDS_RESET:
        myPID->SetMode(MANUAL); 
        control_output = 0.0f; 
        smoothed_angle = 0.0f;   // --- NEW: Reset smoothing variable ---
        motor->reset_beam_angle(); 
        
        Serial.println("Reset complete. Waiting for ball at center...");
        current_state = STATE_WAITING;
        first_read = true; 
        break;

      case STATE_WAITING:
        if (distance_val >= BALL_RESUME_MIN_CM && distance_val <= BALL_RESUME_MAX_CM) {
          Serial.printf("Ball detected at %.1f cm. Resuming balance!\r\n", distance_val);
          myPID->SetMode(AUTOMATIC);
          current_state = STATE_BALANCING;
        } else if (!system_running) {
          motor->set_angle(0.0f); 
        }
        break;
    }
  }

  current_distance = distance_val;
  current_speed = control_output;
  
  delay(50);
}

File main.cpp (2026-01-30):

#include <math.h>
#include <stdio.h>

#include "hardware/gpio.h"
#include "pico/multicore.h"
#include "pico/stdlib.h"

#include "PID_v1.h"

#include "configuration.hpp"

class BBB {
public:
  BBB() {
    gpio_init(TRIGGER_PIN);
    gpio_set_dir(TRIGGER_PIN, GPIO_OUT);

    gpio_init(ECHO_PIN);
    gpio_set_dir(ECHO_PIN, GPIO_IN);

    gpio_init(MOTOR_STEP_PIN);
    gpio_set_dir(MOTOR_STEP_PIN, GPIO_OUT);

    gpio_init(MOTOR_DIR_PIN);
    gpio_set_dir(MOTOR_DIR_PIN, GPIO_OUT);
  }

  /*
   * Reads the sensor distance in cm
   */

  double readSensor(void) {

    absolute_time_t start_time, end_time;
    const uint64_t sensor_timeout_time = 2 * 1e6; // us
    const double speed_of_sound = 0.0343;         // cm/us
    double distance;

    gpio_put(TRIGGER_PIN, 0);
    sleep_us(2); // Sleep just a little bit

    // Send a request to read the sensor
    gpio_put(TRIGGER_PIN, 1);
    sleep_us(SENSOR_TRIGGER_TIME);
    gpio_put(TRIGGER_PIN, 0);

    //
    //
    while (gpio_get(ECHO_PIN) == 0)
      ;
    start_time = get_absolute_time();
    while (gpio_get(ECHO_PIN) == 1)
      ;
    end_time = get_absolute_time();

    int64_t duration_us = absolute_time_diff_us(start_time, end_time);

    distance = duration_us * speed_of_sound / 2.0f;
    return distance;
  }

  double findMotorPeriod(double rpm) {
    double frequency;

    frequency = rpm / ((STEP_ANGLE / 360.f) * 60.f);

    return 1.0 / frequency;
  }

private:
};

int MOTOR_PWM = 0;
int MOTOR_ENABLED = 1;
int MOTOR_DIRECTION = 0;

int clamp(int x, int min, int max) {

  if (x >= max) {
    return max;
  } else if (x <= min) {
    return min;
  }

  return x;
}

void runPWM() {

  int step_signal = 0;
  // Max has to be 740
  double upper_bound = 400;
  double lower_bound = 100;
  double bound = 0;

  while (true) {

    if (MOTOR_ENABLED == 1) {
      /*
         if (bound <= 30 && bound >= 0) {
         step_signal = ~step_signal;
         gpio_put(MOTOR_STEP_PIN, step_signal);
         sleep_us((MOTOR_PWM));



         }
         */

      if (MOTOR_DIRECTION == COUNTER_CLOCKWISE && bound <= upper_bound) {
        bound += STEP_ANGLE / 2;
        step_signal = ~step_signal;
        gpio_put(MOTOR_STEP_PIN, step_signal);
        sleep_us((MOTOR_PWM));

      } else if (MOTOR_DIRECTION == CLOCKWISE && bound >= lower_bound) {
        bound -= STEP_ANGLE / 2;
        step_signal = ~step_signal;
        gpio_put(MOTOR_STEP_PIN, step_signal);
        sleep_us((MOTOR_PWM));
      }
    }
  }
}

int main(void) {

  BBB brain;
  float distance;
  float set_point = 12;
  float error = 0;
  double period;
  int step_signal = 0;
  int kl;
  int PWM_MAX = 1200;

  double input, output;

  PID mypid(&distance, &error, &set_point, 30, 2, 3, DIRECT);
  mypid.SetMode(AUTOMATIC);
  mypid.SetOutputLimits(-PWM_MAX, PWM_MAX);
  stdio_init_all();

  multicore_launch_core1(runPWM);

  gpio_put(MOTOR_DIR_PIN, 1);

  absolute_time_t last_time = get_absolute_time();
  absolute_time_t ultra_sonic_timer = get_absolute_time();
  while (true) {

    distance = brain.readSensor();
    if (distance < 23 && distance > 0.15) {
      // error = -(distance - set_point);
      // error = pid.calculate_error(error, 0.1);
      mypid.Compute();

      MOTOR_PWM = PWM_MAX - abs(error);
      MOTOR_ENABLED = 1;

      if ((set_point) - (distance) <= 0) {
        MOTOR_DIRECTION = COUNTER_CLOCKWISE;
        gpio_put(MOTOR_DIR_PIN, COUNTER_CLOCKWISE);
      }

      else {
        MOTOR_DIRECTION = CLOCKWISE;
        gpio_put(MOTOR_DIR_PIN, CLOCKWISE);
      }
      printf(
          "Distance: %.2f cm | Error: %.6f | Period = %d us | Direction: %s\n",
          distance, error, MOTOR_PWM, MOTOR_DIRECTION ? "CW" : "CCW");
    }
  }
  return 0;
}

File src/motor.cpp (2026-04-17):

#include "motor.hpp"
#include "configuration.hpp"
#include "pico/stdlib.h"
#include <math.h>

MOTOR::MOTOR(int step_pin, int dir_pin) { set_motor_pins(step_pin, dir_pin); }

void MOTOR::set_angle(float angle) {

  int new_angle = angle / 0.225;

  if (abs(new_angle - current_angle) > 1) {
    change_angle(new_angle - current_angle);
    current_angle = current_angle + (new_angle - current_angle);
  }
}

void MOTOR::set_motor_pins(int step_pin, int dir_pin) {
  STEP_PIN = step_pin;
  DIR_PIN = dir_pin;
}

float MOTOR::get_current_angle() { return current_angle * angle_conversion; }

// void MOTOR::set_pulsewidth_us(uint us) { pulsewidth = 1000; }
void MOTOR::set_pulsewidth_us(uint us) { pulsewidth = us; }

void MOTOR::reset_beam_angle() {
  // save the normal balancing speed
  uint original_pulsewidth = pulsewidth;

  // set a slower speed for the reset routine
  pulsewidth = 3000; // larger is slower

  // run the reset movements
  // changing the angle by 120 guarantees that the beam will be on the edge
  change_angle(50 / angle_conversion);
  sleep_ms(1000);
  change_angle(-19 / angle_conversion);
  sleep_ms(1000);
  current_angle = 0;

  // restore the fast speed so the PID loop works properly afterwards
  pulsewidth = original_pulsewidth;
}

void MOTOR::change_angle(int angle) {
  int new_angle = abs(angle);
  int counter = 0;

  if (angle > 0) {
    gpio_put(DIR_PIN, CLOCKWISE);
  } else {
    gpio_put(DIR_PIN, COUNTER_CLOCKWISE);
  }
  sleep_us(10);

  while (counter < new_angle) {
    gpio_put(STEP_PIN, 1);
    sleep_us(pulsewidth / 2);
    gpio_put(STEP_PIN, 0);
    sleep_us(pulsewidth / 2);

    counter++;
  }
}

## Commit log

2026-01-30 fix: make small updates
    [main.cpp]
2026-01-30 feat: finish rough migration to new board and sensor
2026-02-02 feat: switch to using submodules
2026-02-03 feat: add pin configuration
2026-02-04 feat: update PID logic
2026-03-03 fix: update pin documentation
2026-03-04 fix: migrate to using built-in PWM
    [configuration.hpp, main.cpp]
2026-03-25 fix: update pin tables in README.md
2026-03-28 testing code for the motor driver
2026-03-28 Made a working ball and beam robot with this setup so far. Made a class for the motor with all of its functions.
2026-03-29 Changed the code a bit by adding a funciton to the motor class that resets the motor angle under MOTOR::reset_beam_angle() that gets the beam to an approximate 0 angle, that was determined through em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
    [configuration.hpp, main.cpp]
2026-03-29 Refactored the code to have the motor class take its own seperate cpp & hpp files. This should make the code a lot easier to modify and compile
2026-04-03 feat: add flowchart
2026-04-10 feat: add circuit diagram
2026-04-15 feat: revamp touchscreen ui, add buttons, and add 3-point rolling average to ToF sensor readings
2026-04-17 possible fix: switch a pin
    [src.ino]
2026-04-24 feat: add CAD models and some documents
2026-05-02 feat: add PCB files
    [RTV_Robot2_BBB.kicad_pcb, RTV_Robot2_BBB.kicad_sch]
